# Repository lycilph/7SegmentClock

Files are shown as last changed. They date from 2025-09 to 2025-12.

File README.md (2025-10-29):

# Mechanical Clock Project

## Overview
This repository contains the code, schematics, and documentation for building a custom mechanical clock using four digit modules in a 24-hour format. Each digit is driven by a stepper motor for mechanical display, controlled via an ESP32-S3 Super Mini master module over I2C. The project includes homing functionality with Hall effect sensors and LED indicators for status.

The setup is modular, with two digit modules on each side of the master (e.g., left2 ← left1 ← master → right1 → right2). Power is supplied externally at 5V, and modules are connected using JST XH connectors.

**Key Features:**
- 24-hour time display with mechanical digits.
- Stepper motor control for each digit.
- Automatic homing using Hall sensors.
- I2C communication with voltage level shifting for safety.
- Modular design for easy assembly and expansion.

## Components
### Master Module
- ESP32-S3 Super Mini (controls I2C bus and logic).

### Per Digit Module (x4)
- PCF8575 GPIO expander (I2C to GPIO).
- ULN2003 driver board (for stepper control).
- 28BYJ-48 stepper motor (drives the digit mechanism).
- A3144 Hall effect sensor (for homing).
- Red LED (homing in progress indicator).

### Additional Hardware
- External 5V power supply (2A+ recommended).
- Bidirectional I2C level shifter (e.g., BSS138-based, 4-channel) – **critical** to bridge 3.3V (ESP32) and 5V (PCF8575).
- Resistors: 4.7kΩ (I2C pull-ups x4), 10kΩ (A3144 pull-up x4), 330Ω (LED current limiter x4).
- Capacitors: 0.1µF ceramic (decoupling for each IC), 10-100µF electrolytic (at power entry).
- Wires: 20-22 AWG for power/GND; twisted-pair for SDA/SCL.
- Connectors: JST XH 4-pin (5V, GND, SDA, SCL).

## Usage
- Power the system; ESP32 boots and initializes modules.
- Clock syncs via NTP (add WiFi code if desired) or manual set.
- Homing: On startup, each digit homes using Hall sensor; LED blinks during process.
- Display updates every minute via steppers.
---

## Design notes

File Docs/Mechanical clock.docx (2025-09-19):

# Project Architecture Overview (Google AI Studio)

This design uses a logic level shifter to create two distinct voltage zones:

- 3.3V Control Zone: The ESP32-S3 microcontroller.
- 5V Actuator Zone: All four-digit modules, including their PCF8575 GPIO expanders, stepper drivers, sensors, and LEDs.

This approach eliminates the need for individual voltage dividers on each module, resulting in a cleaner and more reliable build.

### Required Components Checklist

Control:

- ESP32-S3 Super Mini (x1)
- Bi-directional Logic Level Shifter (1x, 2-channel minimum)

Digit Modules (x4 of each):

- PCF8575 I2C GPIO Expander
- ULN2003 Stepper Driver Board
- 28BYJ-48 Stepper Motor
- A3144 Hall Effect Sensor
- Red LED

Passive Components:

- Power Supply: 5V DC, rated for 2 Amps or more.
- 330Ω Resistors (x4): For the homing LEDs.
- 4.7kΩ Resistors (x4): For I2C pull-ups (2 for the 3.3V side, 2 for the 5V side). Note: Some shifter boards have built-in resistors; check your board’s documentation.
- 0.1µF (100nF) Ceramic Capacitors (Optional but Recommended): Place one next to each IC (ESP32 and each PCF8575) for power stability.

### Wiring Instructions

#### Step 1: Power Distribution

1. Connect your 5V/2A power supply to create your main 5V Rail and GND Rail.
2. Power the ESP32-S3:
  - Connect the 5V Rail to the VIN (or 5V) pin.
  - Connect the GND Rail to the GND pin.
3. The 3V3 pin on the ESP32 is now your 3.3V Source.

#### Step 2: Logic Level Shifter & I2C Bus

This shifter bridges the 3.3V ESP32 and the 5V modules.

1. Power the Shifter:
  - HV (High Voltage) -> 5V Rail
  - LV (Low Voltage) -> ESP32 3V3 pin
  - GND -> GND Rail
2. Connect the ESP32 (Low Voltage Side):
  - ESP32 SDA pin -> Shifter LV1
  - ESP32 SCL pin -> Shifter LV2
  - Add a 4.7kΩ pull-up resistor from LV1 to 3.3V.
  - Add a 4.7kΩ pull-up resistor from LV2 to 3.3V.
3. Connect the Modules (High Voltage Side):
  - Shifter HV1 -> SDA pin of all four PCF8575 modules.
  - Shifter HV2 -> SCL pin of all four PCF8575 modules.
  - Add a 4.7kΩ pull-up resistor from HV1 to the 5V Rail.
  - Add a 4.7kΩ pull-up resistor from HV2 to the 5V Rail.

#### Step 3: Set Unique I2C Addresses

This is critical. Each PCF8575 must have a unique address. Set them by connecting the address pins (A0, A1, A2) to either GND (for 0) or 5V (for 1).

Module | A2 | A1 | A0 | I2C Address
Digit 1 | GND | GND | GND | 0x20
Digit 2 | GND | GND | 5V | 0x21
Digit 3 | GND | 5V | GND | 0x22
Digit 4 | 5V | GND | GND | 0x23

You can use other combinations, just ensure each one is unique.

#### Step 4: Wiring a Single Digit Module (Repeat 4 times)

All components in the module run on 5V.

1. Power:
  - PCF8575 VCC -> 5V Rail
  - ULN2003 + -> 5V Rail
  - A3144 VCC -> 5V Rail
  - Connect all GND pins on the module to the common GND Rail.
2. Connections:
  - Stepper Motor:
    - Connect the 28BYJ-48 plug into the ULN2003 driver board.
    - PCF8575 P0 -> ULN2003 IN1
    - PCF8575 P1 -> ULN2003 IN2
    - PCF8575 P2 -> ULN2003 IN3
    - PCF8575 P3 -> ULN2003 IN4
  - Homing Sensor (A3144):
    - A3144 Output -> PCF8575 input pin (e.g., P5). No other components are needed.
  - Homing LED:
    - ~~PCF8575 output pin (e.g.,~~ ~~P4~~~~) ->~~ ~~330Ω Resistor~~ ~~-> LED Anode (+)~~
    - ~~LED Cathode (-) ->~~ ~~GND Rail~~
    - 5V → 330Ω resistor → LED anode; cathode to PCF8575 output (e.g., P05). Active-low.

### Final Sanity Check

Before powering on, review these critical points:

1. Power Supply: Ensure your 5V power supply can provide at least 2 Amps. This is the most common cause of instability when motors are running.
2. No 5V to ESP32: Confirm that no 5V signals are connected directly to any ESP32 I/O pin. The logic level shifter is the only component bridging the two voltage levels.
3. Unique I2C Addresses: Double-check the A0/A1/A2 wiring on each of the four PCF8575 modules. If any two are the same, the I2C bus will fail.
4. Grounds are Common: All components (ESP32, shifter, and all four modules) must share a common ground connection.

# Extra (from ChatGPT)

Specific resistors & capacitors to use (concrete)

- I²C pull-ups: 10 kΩ to 3.3 V on ESP side; 4.7 kΩ to 5 V on module side. If bus is long or many devices, use 4.7 kΩ (or 2.2 kΩ for 400 kHz).
- PCF8575 INT pull-up: 10 kΩ to 3.3 V (ESP side).
- Hall sensor (A3144) output pull-up: if you connect A3144 OUT to a PCF8575 input, pull-up to 5 V (10 kΩ) on module (optional if you trust PCF8575 input behavior). If you connect A3144 OUT to ESP32 directly, use 10 kΩ to 3.3 V and confirm open-collector nature.
- LED resistor (5 V drive): 1 kΩ (≈3 mA) or 470 Ω (≈6–7 mA) depending on desired brightness.
- Decoupling: 100 nF ceramic at every IC power pin. Motor bulk: 470–1000 µF electrolytic on the 5 V rail near the motor feed.
- Small 0.1 µF across the A3144 VCC–GND on the module to stabilize sensor supply.

# Checking Level-shifter for built-in pull-ups (Gemini)

Yes, you can absolutely be sure by using a multimeter. It's the perfect tool for the job.

You can also often tell just by looking at the board.

## Using a Multimeter multimeter

Here is the step-by-step process. This must be done with the level shifter completely disconnected and unpowered.

1. Prepare Your Multimeter
  - Set your multimeter to measure resistance (Ω).
  - Choose a range like 20kΩ, as most built-in pull-up resistors are between 1kΩ and 10kΩ.
2. Test the High Voltage (HV) Side
  - Place one probe on the HV pin.
  - Place the other probe on the SDA_HV pin (sometimes labeled HV2).
  - Check the reading.
  - Now, keep the first probe on the HV pin and move the second probe to the SCL_HV pin (sometimes labeled HV1).
  - Check the reading.
3. Test the Low Voltage (LV) Side
  - Place one probe on the LV pin.
  - Place the other probe on the SDA_LV pin (sometimes labeled LV2).
  - Check the reading.
  - Now, keep the first probe on the LV pin and move the second probe to the SCL_LV pin (sometimes labeled LV1).
  - Check the reading.

## Interpreting the Results 💡

- If you see a stable value between 1kΩ and 10kΩ: Congratulations, a pull-up resistor is present on that pin. A reading of "10.0" on the 20kΩ scale means you have a 10kΩ resistor.
- If your meter reads "OL" (Over Limit), "infinite," or just doesn't change from its default state: There is no pull-up resistor connecting those two pins. You will need to add your own.

You should get a consistent reading for both the SDA and SCL pins on a given side (e.g., both pins on the HV side will have 10kΩ pull-ups).

## A Quick Visual Check 👀

You can often spot the resistors just by looking.

Look for small, black surface-mount (SMD) components near the pins. They are usually marked with a numerical code. For a 10kΩ resistor, you will typically see the number "103" (which means 10 followed by 3 zeros, or 10,000). You can follow the copper traces on the board to see if they connect the SDA/SCL pins to the HV/LV pins through these components.

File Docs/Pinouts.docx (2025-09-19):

# Pinouts

## ESP32-S3 Super mini

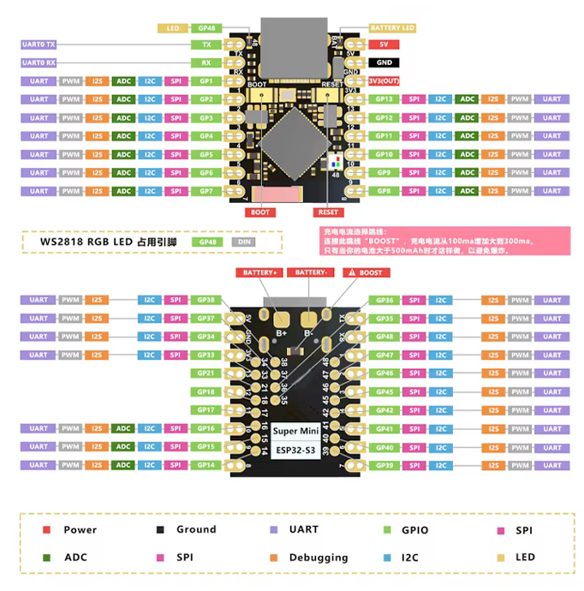
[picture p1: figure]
ESP32-S3 Super Mini pinout
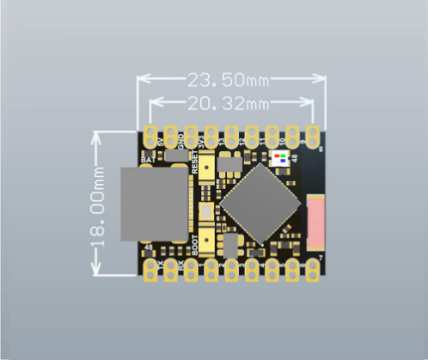
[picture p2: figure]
ESP32-S3 Super Mini dimensions - height, width

## PCF8575

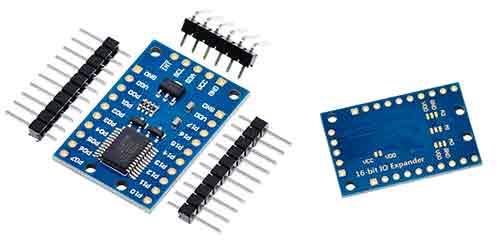
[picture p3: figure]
arduino-pcf8575-componente
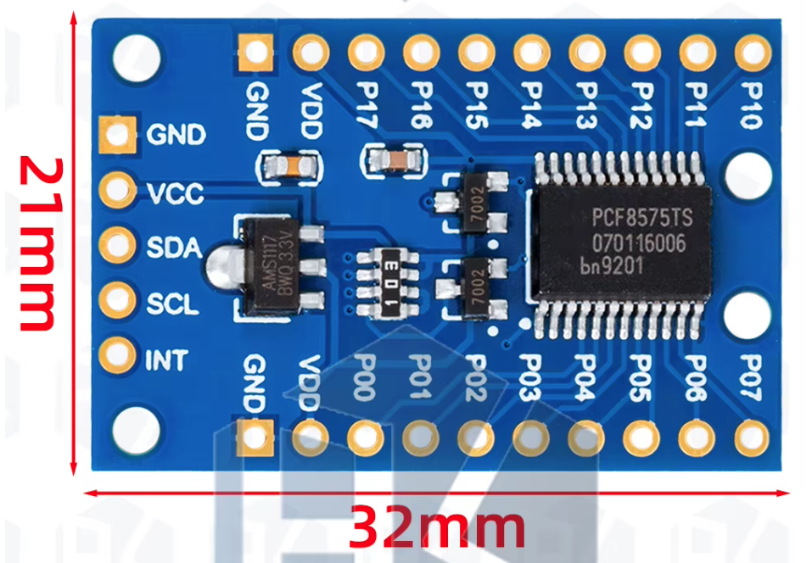
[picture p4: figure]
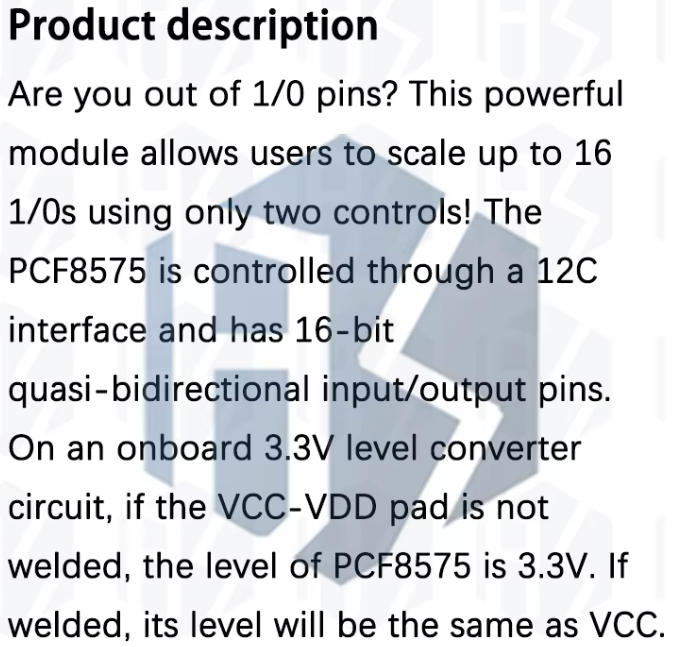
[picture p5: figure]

## A3144

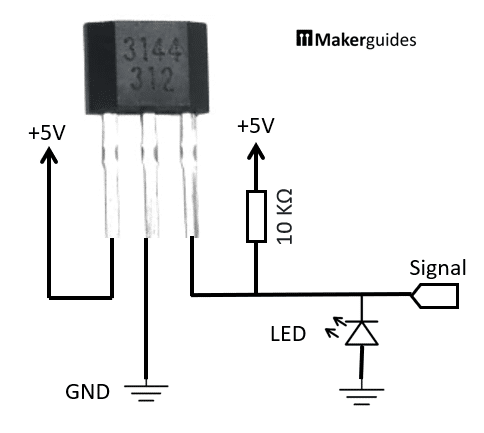
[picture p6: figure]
Testing the A3144 Hall Effect Sensor

## ULN2003

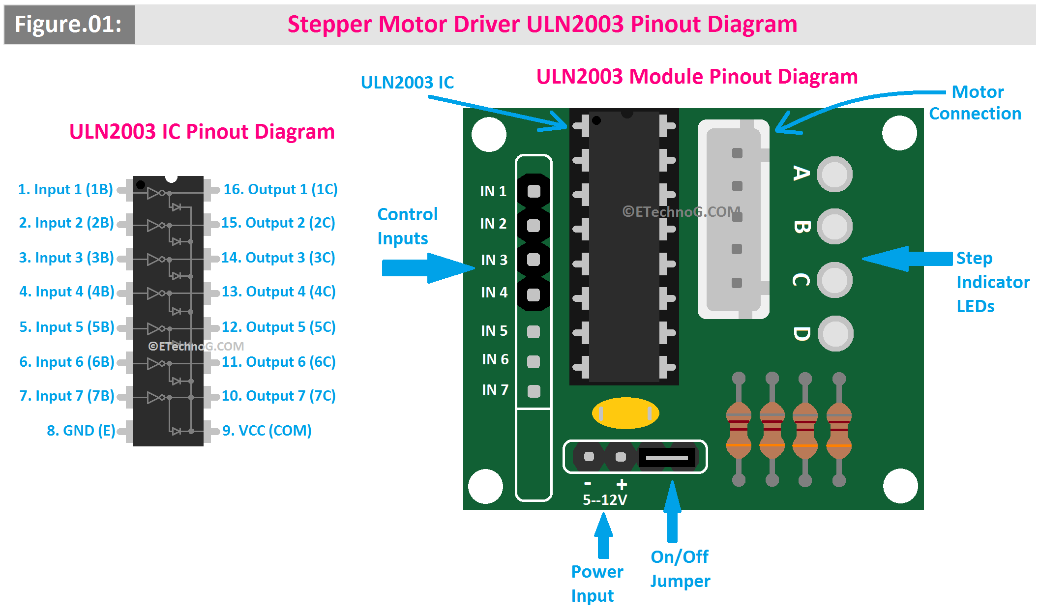
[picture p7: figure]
ULN2003 IC Pinout Diagram, ULN2003 Module Pinout Diagram

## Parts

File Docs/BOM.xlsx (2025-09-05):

Item | # | Price | Total | Link
28BYJ-48 Stepper motor | 5 | 11.88 | 57.96 | https://www.aliexpress.com/item/1005005929104242.html?curPageLogUid=ijdTWuI513CS
PCF8575 | 5 | 15.62 | 54.79 | https://www.aliexpress.com/item/1005009410052950.html?curPageLogUid=l2r6LPoUxHaU
A3144 | 10 | 13.23 | 13.23 | https://www.aliexpress.com/item/1005006136921399.html?curPageLogUid=vVF7NFhDA8yi
N52 5x3 magnets | 50 | 31.35 | 31.35 | https://www.aliexpress.com/item/1005009339285539.html?curPageLogUid=vOYvfErc0nGl
USB-c connector | 5 | 17.12 | 17.12 | https://www.aliexpress.com/item/1005007469640237.html?productId=1005007469640237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
Bearings 608zz | 10 | 22.04 | 22.04 | https://www.aliexpress.com/item/1005008612618353.html?curPageLogUid=ml2DoczdEAmw
RTC DS1307 | 2 | 9.81 | 19.62 | https://www.aliexpress.com/item/1005007143542894.html?curPageLogUid=M9aB6QRXBudq
Wires | 1 | 79.27 | 79.27 | https://www.aliexpress.com/item/1005009726416788.html?curPageLogUid=W2luivYyj2qX
JST connector set | 1 | 126.8 | 126.8 | https://www.aliexpress.com/item/4001142557350.html?curPageLogUid=jYMhtkVZFTlC
M3 Bolts
 |  |  | 422.18

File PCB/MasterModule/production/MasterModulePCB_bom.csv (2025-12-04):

Designator | Footprint | Quantity | Value | LCSC Part #
C1 | C_Radial_D8.0mm_H11.5mm_P3.50mm | 1 | 1000uf
C2, C3 | C_Disc_D3.0mm_W2.0mm_P2.50mm | 2 | 100nf
CON1 | JST_Connector_Footprint | 1 | Male Connector
CON2 | JST_Connector_Footprint | 1 | Femail Connector
L1 | PinHeader_1x02_P2.54mm_Vertical | 1 | Yellow LED
L2 | PinHeader_1x02_P2.54mm_Vertical | 1 | Green LED
L3 | PinHeader_1x02_P2.54mm_Vertical | 1 | Power LED
P1 | Power_Connection_Footprint | 1 | USB Power
R1, R2 | R_Axial_DIN0204_L3.6mm_D1.6mm_P7.62mm_Horizontal | 2 | 220
R3 | R_Axial_DIN0204_L3.6mm_D1.6mm_P7.62mm_Horizontal | 1 | 330
R4, R5, R6, R7 | R_Axial_DIN0204_L3.6mm_D1.6mm_P7.62mm_Horizontal | 4 | 4k7
RTC1 | RTC_Module_Footprint | 1 | Real Time Clock
U1 | I2C_Level_Shifter | 1 | I2C Level Shifter
U2 | PinHeader_1x05_P2.54mm_Vertical | 1 | ESP32
U3 | PinHeader_1x05_P2.54mm_Vertical | 1 | ESP32 Signals
U4 | PinHeader_1x06_P2.54mm_Vertical | 1 | Controls

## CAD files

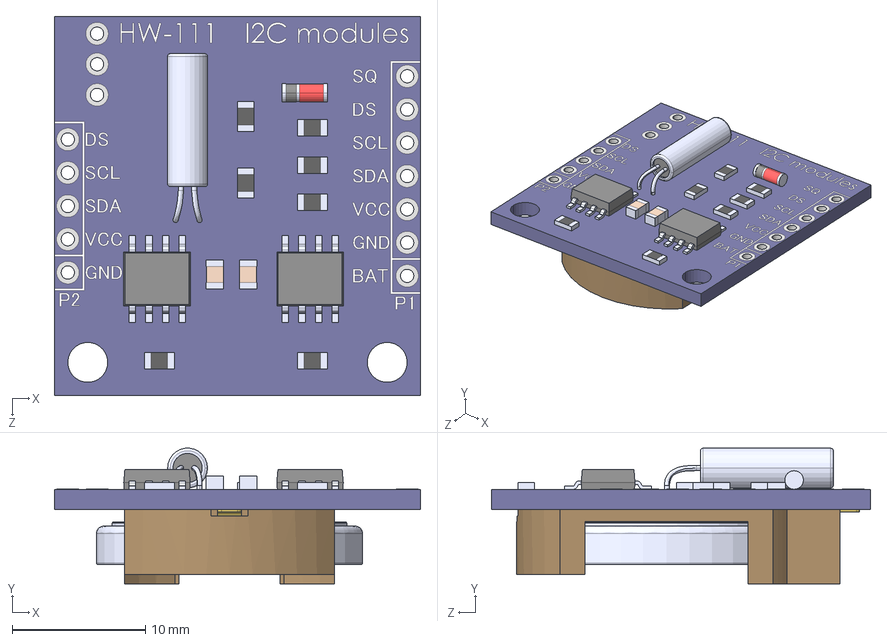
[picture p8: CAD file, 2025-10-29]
CAD/RTCmodule_DS1307.STEP
27.5 x 10.2 x 28.5 mm
HW-111_MainBoad
IC_DS1307Z_1901GM_153AA x 2
セラミックコンデンサs x 2
チップコンデンサ x 7
Oscillator
Battery Holder_LIR2032
TerminalPlus
TerminalMinus
LIR2032_Battery
D1daiord

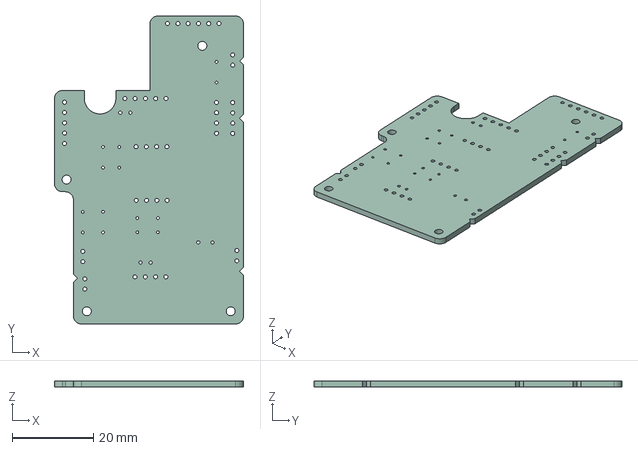
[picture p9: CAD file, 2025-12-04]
PCB/MasterModule.step
46.7 x 76.0 x 1.51 mm

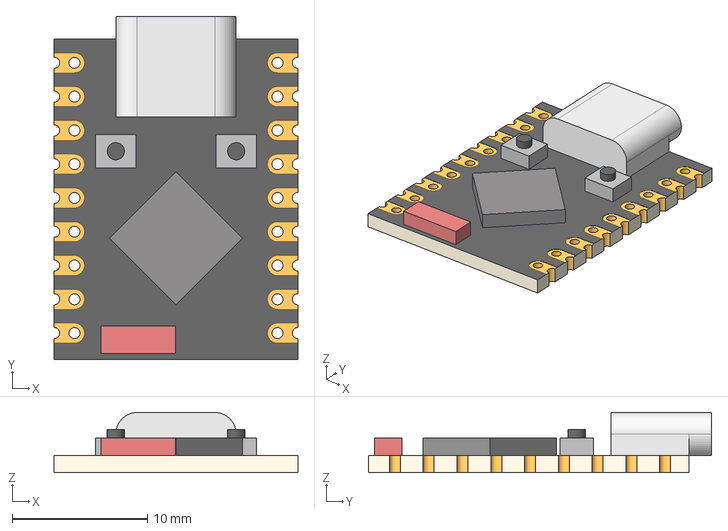
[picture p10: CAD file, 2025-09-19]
CAD/ESP32S3 Super Mini.step
18.0 x 25.4 x 4.45 mm

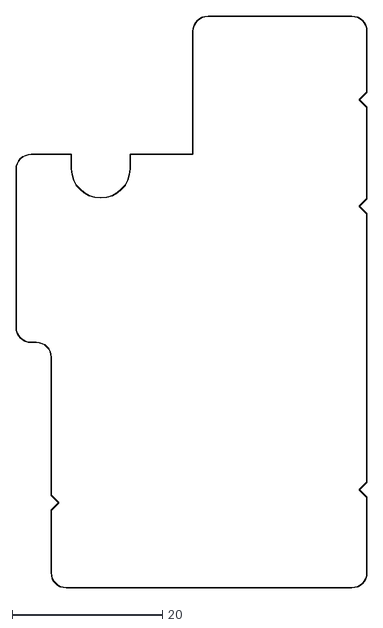
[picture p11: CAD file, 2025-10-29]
PCB/PCB Outline.dxf
46.7 x 76.0

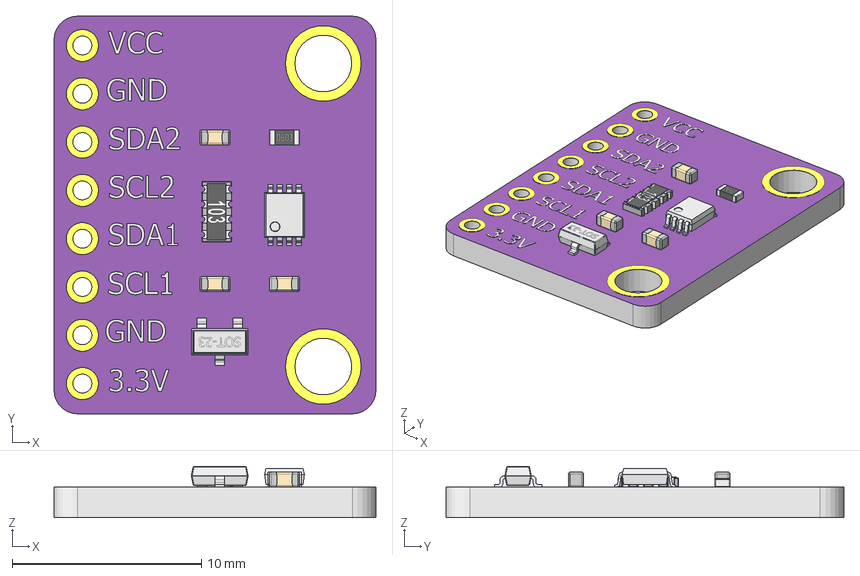
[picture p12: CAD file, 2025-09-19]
CAD/pca9306.step
17.0 x 21.0 x 2.70 mm
Board
ť1
ť2 x 2
SOT23-3
C0603_001
C0603_002
C0603_003
VSSSOP8
CAT16-J4

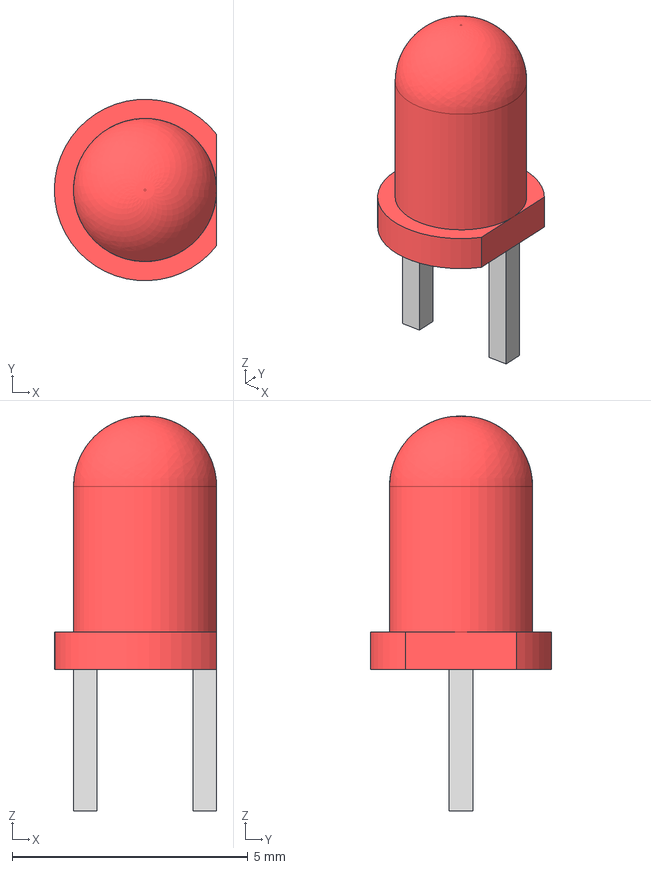
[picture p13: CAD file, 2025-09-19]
CAD/LED 3mm Red 3mm Leads.step
3.45 x 3.85 x 8.38 mm
LEDBody
Lead1Body
Lead2Body

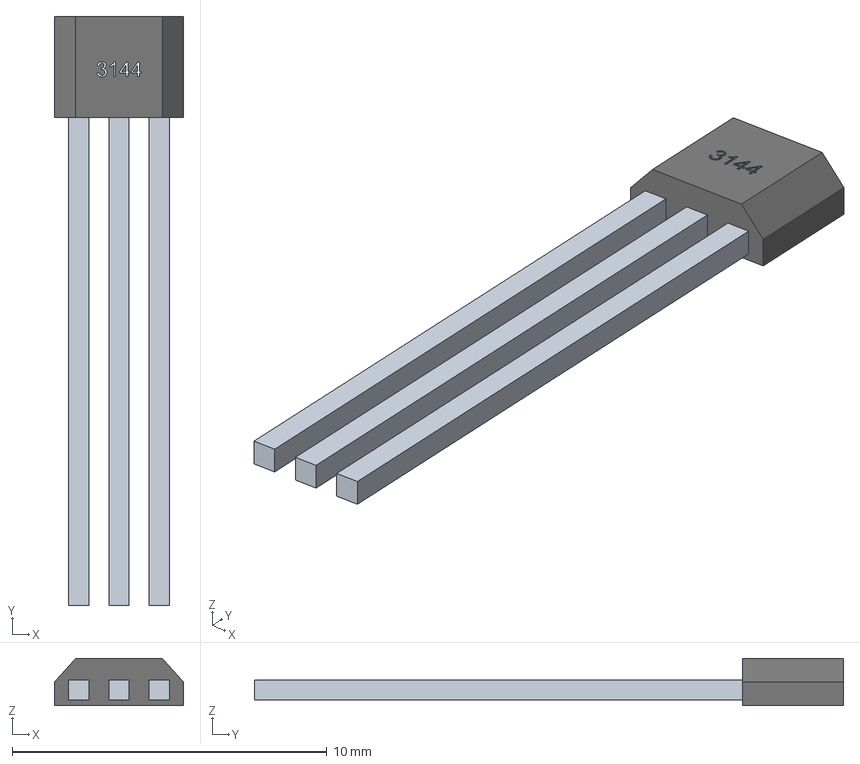
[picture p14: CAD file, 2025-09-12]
CAD/Hall Effect Sensor Sunkee A3144 v4.step
4.10 x 18.7 x 1.50 mm

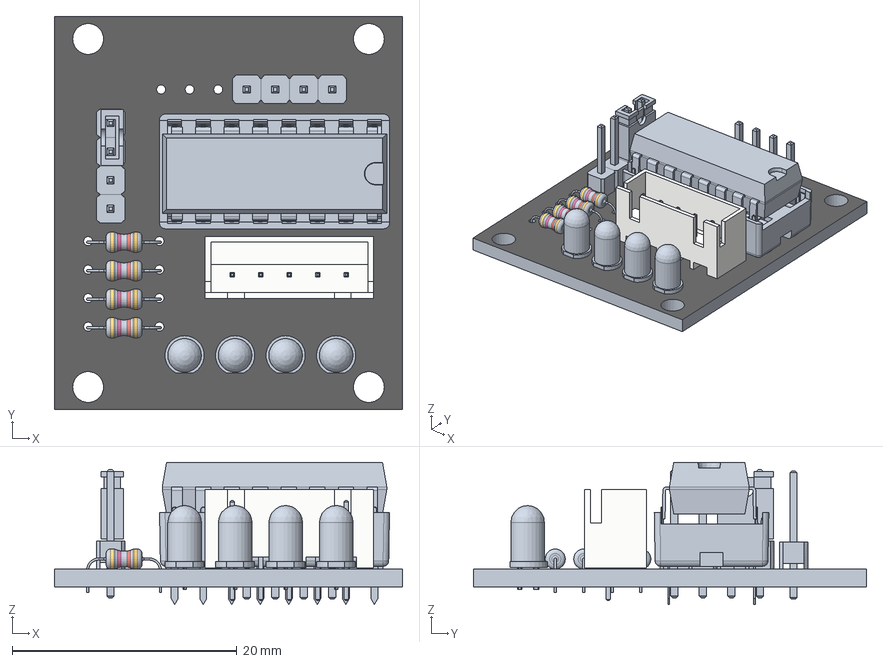
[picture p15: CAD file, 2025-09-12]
CAD/ULN2003 Stepper Driver.stp
31.0 x 35.0 x 12.7 mm
pcb
jumper_connector
r205 x 4
conn_lead x 5
spacer x 4
pin x 4
spacer (1) x 4
pin (1) x 4
LED 3mm x 4
package
lead
housing
pins

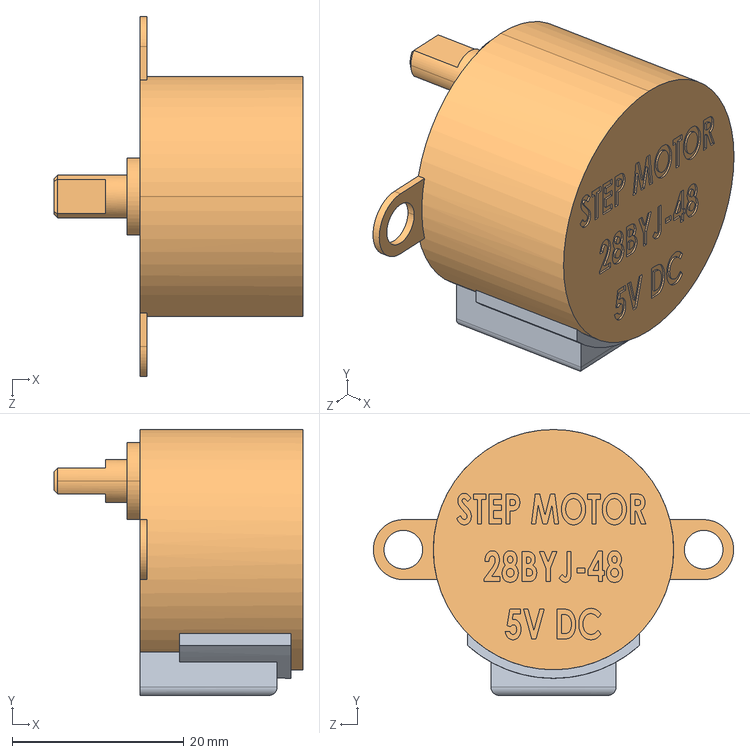
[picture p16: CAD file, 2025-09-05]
CAD/Stepper motor 28BYJ-48 5V.STEP
29.0 x 31.0 x 42.0 mm

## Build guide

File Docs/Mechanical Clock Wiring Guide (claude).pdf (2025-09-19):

## Mechanical Clock Wiring Guide

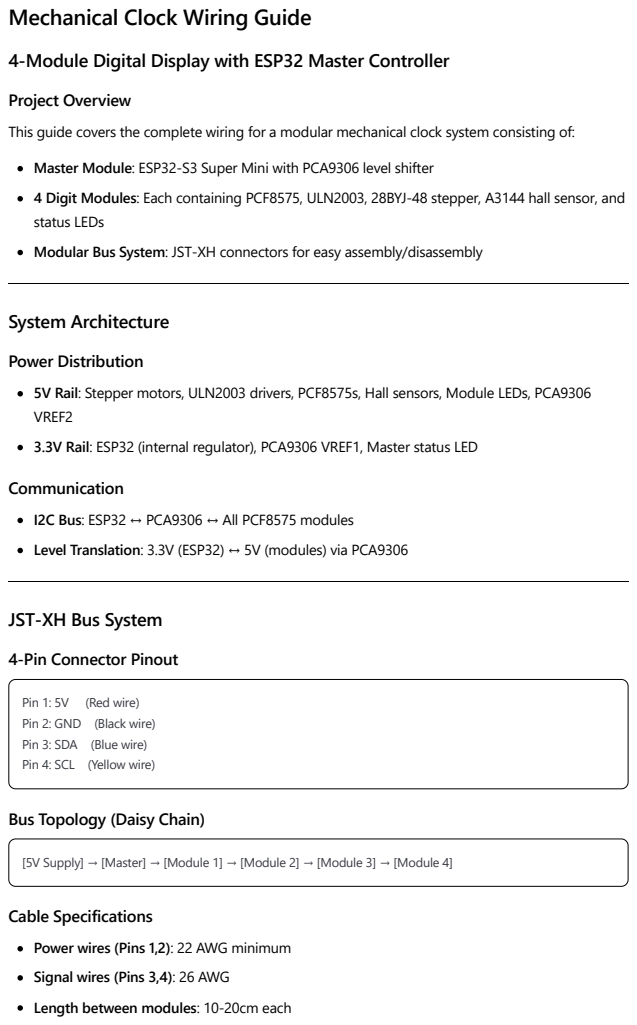
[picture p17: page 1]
System Architecture

4-Module Digital Display with ESP32 Master Controller

Project Overview
This guide covers the complete wiring for a modular mechanical clock system consisting of:
Master Module: ESP32-S3 Super Mini with PCA9306 level shifter
4 Digit Modules: Each containing PCF8575, ULN2003, 28BYJ-48 stepper, A3144 hall sensor, and
status LEDs
Modular Bus System: JST-XH connectors for easy assembly/disassembly

Power Distribution
5V Rail: Stepper motors, ULN2003 drivers, PCF8575s, Hall sensors, Module LEDs, PCA9306
VREF2
3.3V Rail: ESP32 (internal regulator), PCA9306 VREF1, Master status LED
Communication
I2C Bus: ESP32 ↔ PCA9306 ↔ All PCF8575 modules
Level Translation: 3.3V (ESP32) ↔ 5V (modules) via PCA9306

JST-XH Bus System

4-Pin Connector Pinout

Pin 1: 5V (Red wire)
Pin 2: GND (Black wire)
Pin 3: SDA (Blue wire)
Pin 4: SCL (Yellow wire)

Bus Topology (Daisy Chain)

[5V Supply] → [Master] → [Module 1] → [Module 2] → [Module 3] → [Module 4]

Cable Specifications
Power wires (Pins 1,2): 22 AWG minimum
Signal wires (Pins 3,4): 26 AWG
Length between modules: 10-20cm each

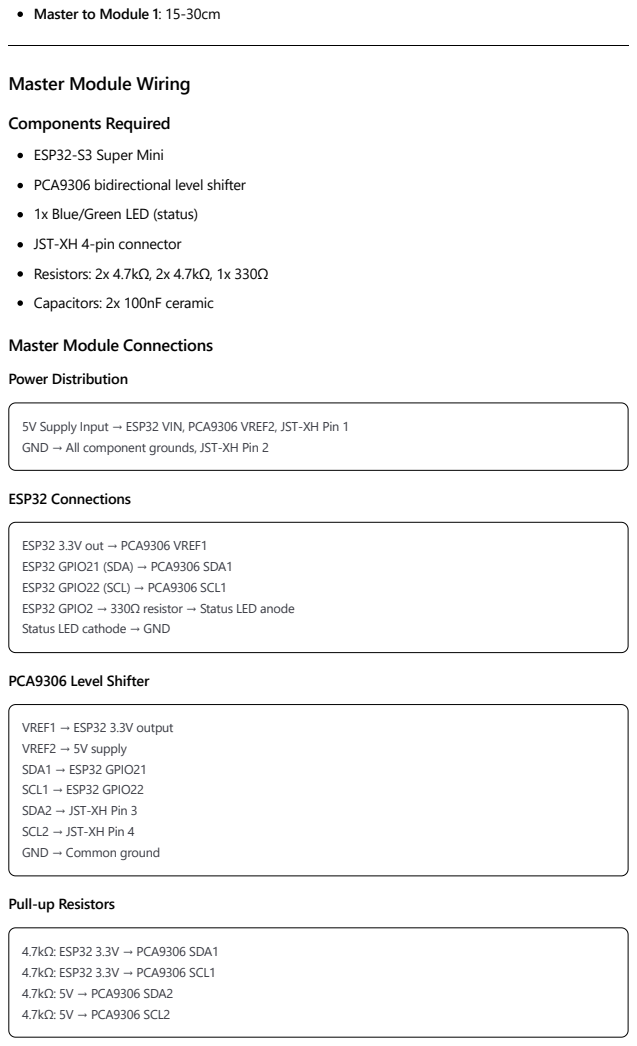
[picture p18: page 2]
ESP32 Connections; PCA9306 Level Shifter; 4.7kΩ: ESP32 3.3V → PCA9306 SDA1 4.7kΩ: ESP32 3.3V → PCA9306 SCL1 4.7kΩ: 5V → PCA9306 SDA2 4.7kΩ: 5V → PCA9306 SCL2

Master to Module 1: 15-30cm

Master Module Wiring

Components Required
ESP32-S3 Super Mini
PCA9306 bidirectional level shifter
1x Blue/Green LED (status)
JST-XH 4-pin connector
Resistors: 2x 4.7kΩ, 2x 4.7kΩ, 1x 330Ω
Capacitors: 2x 100nF ceramic
Master Module Connections
Power Distribution

5V Supply Input → ESP32 VIN, PCA9306 VREF2, JST-XH Pin 1
GND → All component grounds, JST-XH Pin 2

ESP32 3.3V out → PCA9306 VREF1
ESP32 GPIO21 (SDA) → PCA9306 SDA1
ESP32 GPIO22 (SCL) → PCA9306 SCL1
ESP32 GPIO2 → 330Ω resistor → Status LED anode
Status LED cathode → GND

VREF1 → ESP32 3.3V output
VREF2 → 5V supply
SDA1 → ESP32 GPIO21
SCL1 → ESP32 GPIO22
SDA2 → JST-XH Pin 3
SCL2 → JST-XH Pin 4
GND → Common ground

Pull-up Resistors

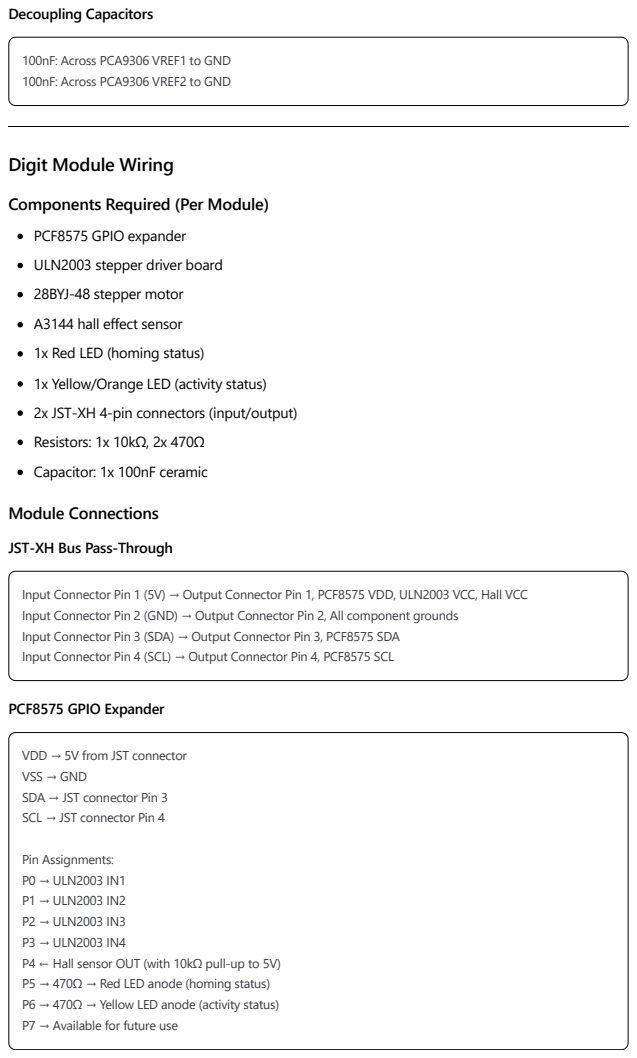
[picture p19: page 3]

Components Required (Per Module)
PCF8575 GPIO expander
ULN2003 stepper driver board
28BYJ-48 stepper motor
A3144 hall effect sensor
1x Red LED (homing status)
1x Yellow/Orange LED (activity status)
2x JST-XH 4-pin connectors (input/output)
Resistors: 1x 10kΩ, 2x 470Ω
Capacitor: 1x 100nF ceramic
Module Connections
JST-XH Bus Pass-Through

Input Connector Pin 1 (5V) → Output Connector Pin 1, PCF8575 VDD, ULN2003 VCC, Hall VCC
Input Connector Pin 2 (GND) → Output Connector Pin 2, All component grounds
Input Connector Pin 3 (SDA) → Output Connector Pin 3, PCF8575 SDA
Input Connector Pin 4 (SCL) → Output Connector Pin 4, PCF8575 SCL

VDD → 5V from JST connector
VSS → GND
SDA → JST connector Pin 3
SCL → JST connector Pin 4

Pin Assignments:
P0 → ULN2003 IN1
P1 → ULN2003 IN2
P2 → ULN2003 IN3
P3 → ULN2003 IN4
P4 ← Hall sensor OUT (with 10kΩ pull-up to 5V)
P5 → 470Ω → Red LED anode (homing status)
P6 → 470Ω → Yellow LED anode (activity status)
P7 → Available for future use

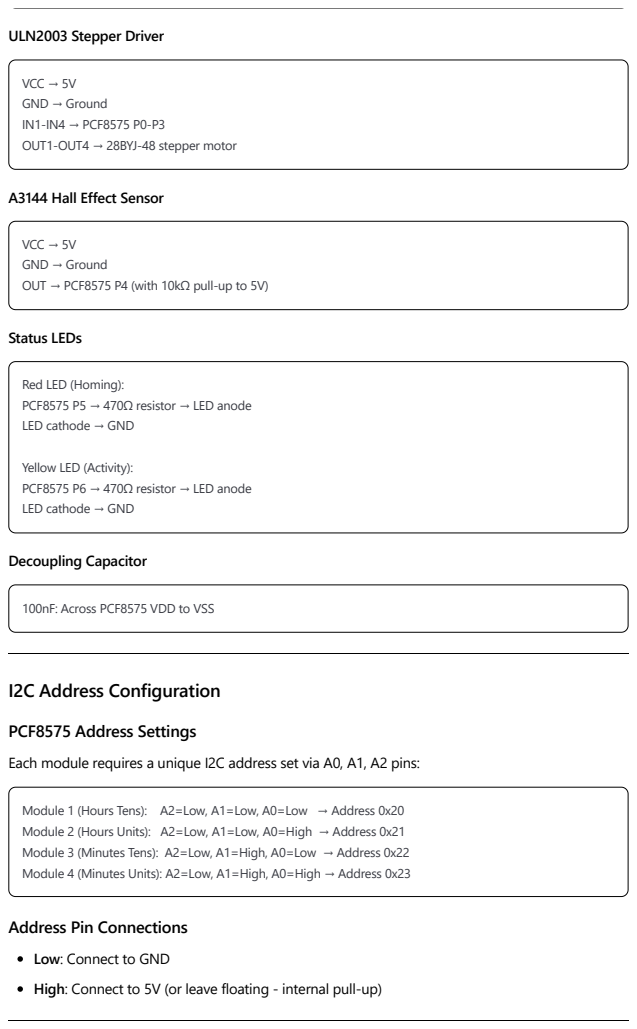
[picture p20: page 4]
ULN2003 Stepper Driver; Status LEDs; Decoupling Capacitor; I2C Address Configuration; VCC → 5V GND → Ground IN1-IN4 → PCF8575 P0-P3 OUT1-OUT4 → 28BYJ-48 stepper motor

A3144 Hall Effect Sensor

VCC → 5V
GND → Ground
OUT → PCF8575 P4 (with 10kΩ pull-up to 5V)

Red LED (Homing):
PCF8575 P5 → 470Ω resistor → LED anode
LED cathode → GND

Yellow LED (Activity):
PCF8575 P6 → 470Ω resistor → LED anode

100nF: Across PCF8575 VDD to VSS

PCF8575 Address Settings
Each module requires a unique I2C address set via A0, A1, A2 pins:

Module 1 (Hours Tens): A2=Low, A1=Low, A0=Low → Address 0x20
Module 2 (Hours Units): A2=Low, A1=Low, A0=High → Address 0x21
Module 3 (Minutes Tens): A2=Low, A1=High, A0=Low → Address 0x22
Module 4 (Minutes Units): A2=Low, A1=High, A0=High → Address 0x23

Address Pin Connections
Low: Connect to GND
High: Connect to 5V (or leave floating - internal pull-up)

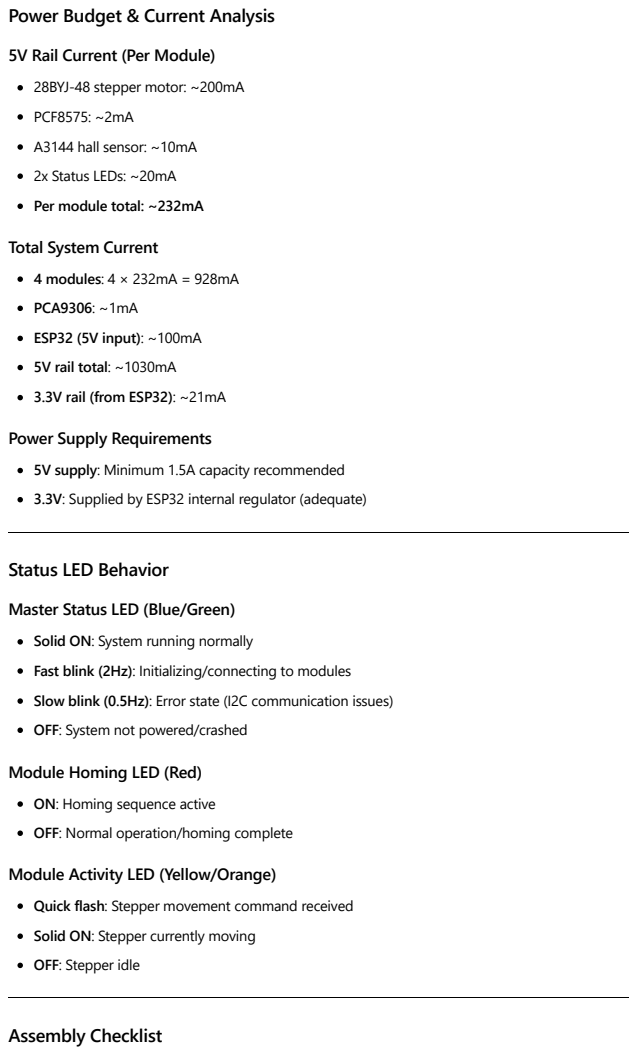
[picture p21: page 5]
Assembly Checklist

Power Budget & Current Analysis

5V Rail Current (Per Module)
28BYJ-48 stepper motor: ~200mA
PCF8575: ~2mA
A3144 hall sensor: ~10mA
2x Status LEDs: ~20mA
Per module total: ~232mA
Total System Current
4 modules: 4 × 232mA = 928mA
PCA9306: ~1mA
ESP32 (5V input): ~100mA
5V rail total: ~1030mA
3.3V rail (from ESP32): ~21mA
Power Supply Requirements
5V supply: Minimum 1.5A capacity recommended
3.3V: Supplied by ESP32 internal regulator (adequate)

Status LED Behavior

Master Status LED (Blue/Green)
Solid ON: System running normally
Fast blink (2Hz): Initializing/connecting to modules
Slow blink (0.5Hz): Error state (I2C communication issues)
OFF: System not powered/crashed
Module Homing LED (Red)
ON: Homing sequence active
OFF: Normal operation/homing complete
Module Activity LED (Yellow/Orange)
Quick flash: Stepper movement command received
Solid ON: Stepper currently moving
OFF: Stepper idle

Before Starting
All JST-XH connectors and cables prepared
Color-coded wires: Red(5V), Black(GND), Blue(SDA), Yellow(SCL) All components and resistor values verified
Multimeter ready for continuity testing

Master Module Assembly
ESP32-S3 Super Mini wired
PCA9306 level shifter installed
Pull-up resistors (4x 4.7kΩ) installed
Status LED and current limiting resistor (330Ω) installed Decoupling capacitors (2x 100nF) installed
JST-XH output connector wired
Power connections tested (5V, GND)
I2C signal continuity verified

Per Module Assembly
PCF8575 I2C address set correctly (A0, A1, A2) JST-XH input and output connectors wired
PCF8575 to ULN2003 connections (P0-P3 to IN1-IN4) Hall sensor wired with pull-up resistor (10kΩ)
Status LEDs with current limiting resistors (2x 470Ω) Decoupling capacitor (100nF) installed
Stepper motor connected to ULN2003 outputs

System Integration
Modules connected in daisy chain order Power supply connected to master module All connections tight and secure
No short circuits (continuity test)
I2C bus pull-ups present on master module only

### Troubleshooting Guide

No Communication with Modules
1. Check 5V and GND on JST-XH bus
2. Verify PCA9306 power (3.3V and 5V sides)
3. Confirm I2C pull-up resistors on master module
4. Test individual modules by connecting directly to master

Module Not Responding

1. Verify unique I2C address settings
2. Check PCF8575 power and ground
3. Disconnect other modules to isolate issue
4. Verify JST-XH connector pinout and wiring

Stepper Motor Issues
1. Check ULN2003 power (5V)
2. Verify PCF8575 P0-P3 to ULN2003 IN1-IN4 connections
3. Confirm motor wiring to ULN2003 OUT1-OUT4
4. Test motor independently with known good driver

Hall Sensor Problems
1. Verify 5V power to sensor
2. Check 10kΩ pull-up resistor to 5V
3. Confirm sensor output to PCF8575 P4
4. Test sensor with magnet and multimeter

Status LED Issues
1. Check current limiting resistor values
2. Verify LED polarity (anode to resistor, cathode to GND)
3. Test PCF8575 output pins with multimeter
4. Replace suspected faulty LEDs

### Component Specifications Summary

ICs and Modules
ESP32-S3 Super Mini: 3.3V logic, built-in 5V→3.3V regulator PCA9306: Bidirectional I2C level shifter (3.3V ↔ 5V) PCF8575: 16-bit I2C GPIO expander, 5V operation ULN2003: Darlington driver array, 5V/500mA per channel 28BYJ-48: 5V stepper motor, ~200mA operation
A3144: Hall effect sensor, 3.3V-5V operation

Passive Components
Pull-up resistors: 4.7kΩ (I2C bus, hall sensor) LED resistors: 330Ω (3.3V), 470Ω (5V)

Decoupling capacitors: 100nF ceramic JST-XH connectors: 4-pin, 3A rating

### Final Notes

Design Benefits
Modular: Each digit module is self-contained and removable Scalable: Easy to add more modules or modify configuration Serviceable: Individual modules can be disconnected for repair Clean: Standardized JST-XH bus eliminates wire mess
Robust: Proper level shifting and power distribution

Safety Considerations
Use appropriate wire gauges for current capacity Ensure all connections are secure before applying power Test continuity before first power-on
Monitor current consumption during initial testing
Use strain relief on all cable connections

Software Considerations
Each PCF8575 module requires unique I2C address Implement proper I2C error handling and timeouts
Use status LEDs to provide visual feedback during operation Consider implementing module auto-discovery for robustness

Document Version: 1.0
Created for: 4-Module Mechanical Clock Project
Last Updated: September 2025

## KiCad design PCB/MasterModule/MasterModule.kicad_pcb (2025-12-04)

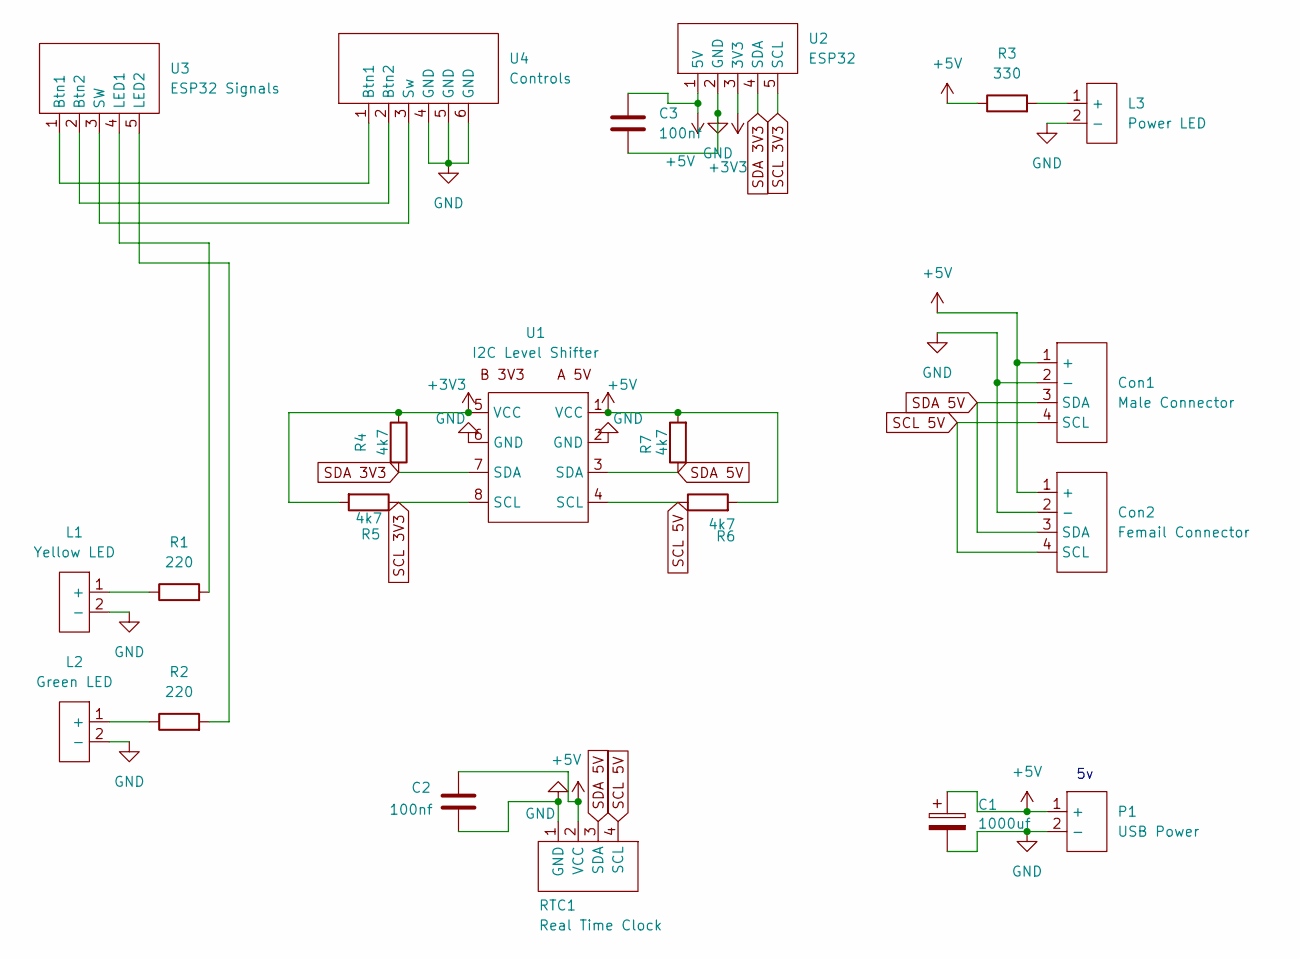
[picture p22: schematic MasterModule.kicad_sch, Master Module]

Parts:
C1: 1000uf; C_Radial_D8.0mm_H11.5mm_P3.50mm
C2, C3: 100nf; C_Disc_D3.0mm_W2.0mm_P2.50mm
Con1: Male Connector; JST_Connector_Footprint
Con2: Femail Connector; JST_Connector_Footprint
L1: Yellow LED; PinHeader_1x02_P2.54mm_Vertical
L2: Green LED; PinHeader_1x02_P2.54mm_Vertical
L3: Power LED; PinHeader_1x02_P2.54mm_Vertical
P1: USB Power; Power_Connection_Footprint
R1, R2: 220; R_Axial_DIN0204_L3.6mm_D1.6mm_P7.62mm_Horizontal
R3: 330; R_Axial_DIN0204_L3.6mm_D1.6mm_P7.62mm_Horizontal
R4, R5, R6, R7: 4k7; R_Axial_DIN0204_L3.6mm_D1.6mm_P7.62mm_Horizontal
RTC1: Real Time Clock; RTC_Module_Footprint
U1: I2C Level Shifter; I2C_Level_Shifter
U2: ESP32; PinHeader_1x05_P2.54mm_Vertical
U3: ESP32 Signals; PinHeader_1x05_P2.54mm_Vertical
U4: Controls; PinHeader_1x06_P2.54mm_Vertical

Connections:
+3V3: R4.1, R5.2, U1.5 (VCC), U2.3 (3V3)
+5V: C1.1, C2.1, C3.1, Con1.1 (+), Con2.1 (+), P1.1 (+), R3.1, R6.2, R7.2, RTC1.2 (VCC), U1.1 (VCC), U2.1 (5V)
GND: C1.2, C2.2, C3.2, Con1.2 (-), Con2.2 (-), L1.2 (-), L2.2 (-), L3.2 (-), P1.2 (-), RTC1.1 (GND), U1.2 (GND), U1.6 (GND), U2.2 (GND), U4.4 (GND), U4.5 (GND), U4.6 (GND)
unnamed: L1.1 (+), R1.1
unnamed: L2.1 (+), R2.1
unnamed: L3.1 (+), R3.2
unnamed: U3.1 (Btn1), U4.1 (Btn1)
unnamed: U3.2 (Btn2), U4.2 (Btn2)
unnamed: R1.2, U3.4 (LED1)
unnamed: R2.2, U3.5 (LED2)
unnamed: U3.3 (SW), U4.3 (Sw)
SCL 3V3: R5.1, U1.8 (SCL), U2.5 (SCL)
SCL 5V: Con1.4 (SCL), Con2.4 (SCL), R6.1, RTC1.4 (SCL), U1.4 (SCL)
SDA 3V3: R4.2, U1.7 (SDA), U2.4 (SDA)
SDA 5V: Con1.3 (SDA), Con2.3 (SDA), R7.1, RTC1.3 (SDA), U1.3 (SDA)

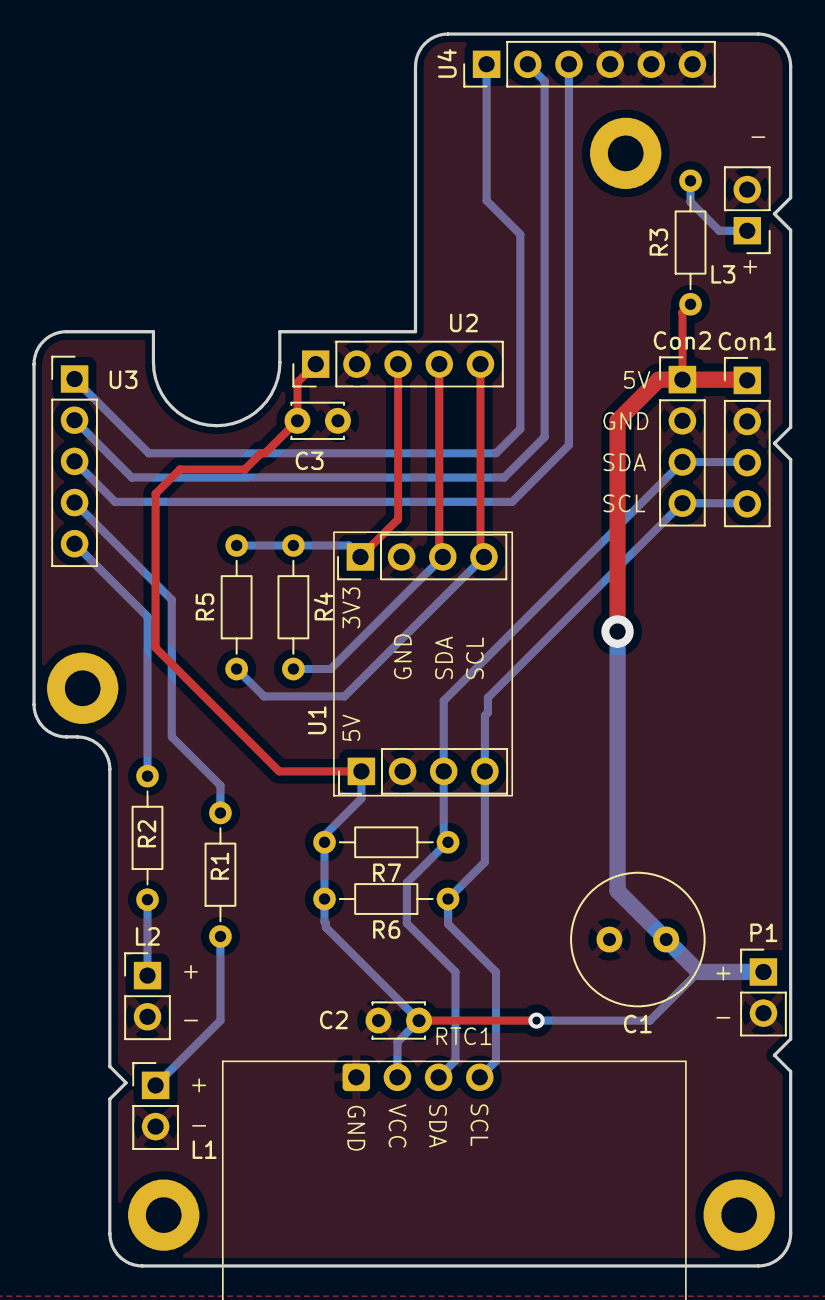
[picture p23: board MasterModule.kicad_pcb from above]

Board: 2 copper layers, 46.7 x 76.0 mm, 21 parts (0 on the bottom side), 15 nets.

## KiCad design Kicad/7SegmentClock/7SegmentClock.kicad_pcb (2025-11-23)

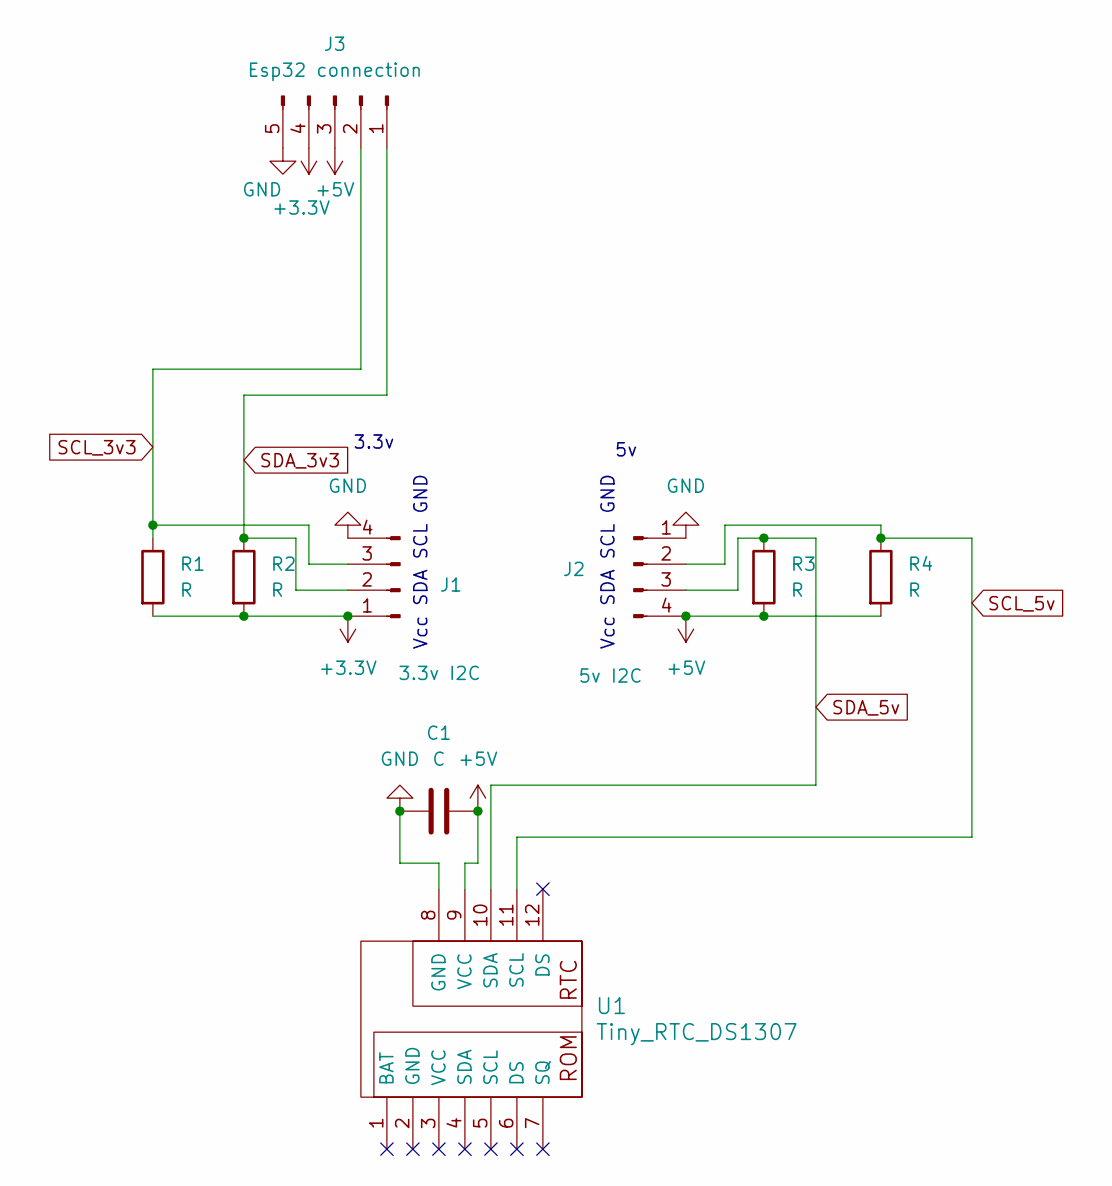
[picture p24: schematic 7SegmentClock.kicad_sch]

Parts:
C1: C; C_Disc_D3.0mm_W1.6mm_P2.50mm
J1: 3.3v I2C; PinHeader_1x04_P2.54mm_Vertical
J2: 5v I2C; PinHeader_1x04_P2.54mm_Vertical
J3: Esp32 connection; PinHeader_1x05_P2.54mm_Vertical
R1, R2, R3, R4: R; R_Axial_DIN0204_L3.6mm_D1.6mm_P5.08mm_Horizontal
U1: Tiny_RTC_DS1307

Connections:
+3.3V: J1.1, J3.4, R1.2, R2.2
+5V: C1.2, J2.4, J3.3, R3.2, R4.2, U1.9 (VCC)
GND: C1.1, J1.4, J2.1, J3.5, U1.8 (GND)
unnamed: J1.2, J3.1, R2.1
unnamed: J1.3, J3.2, R1.1
unnamed: J2.2, R4.1, U1.11 (SCL)
unnamed: J2.3, R3.1, U1.10 (SDA)

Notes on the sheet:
3.3v
Vcc SDA SCL GND

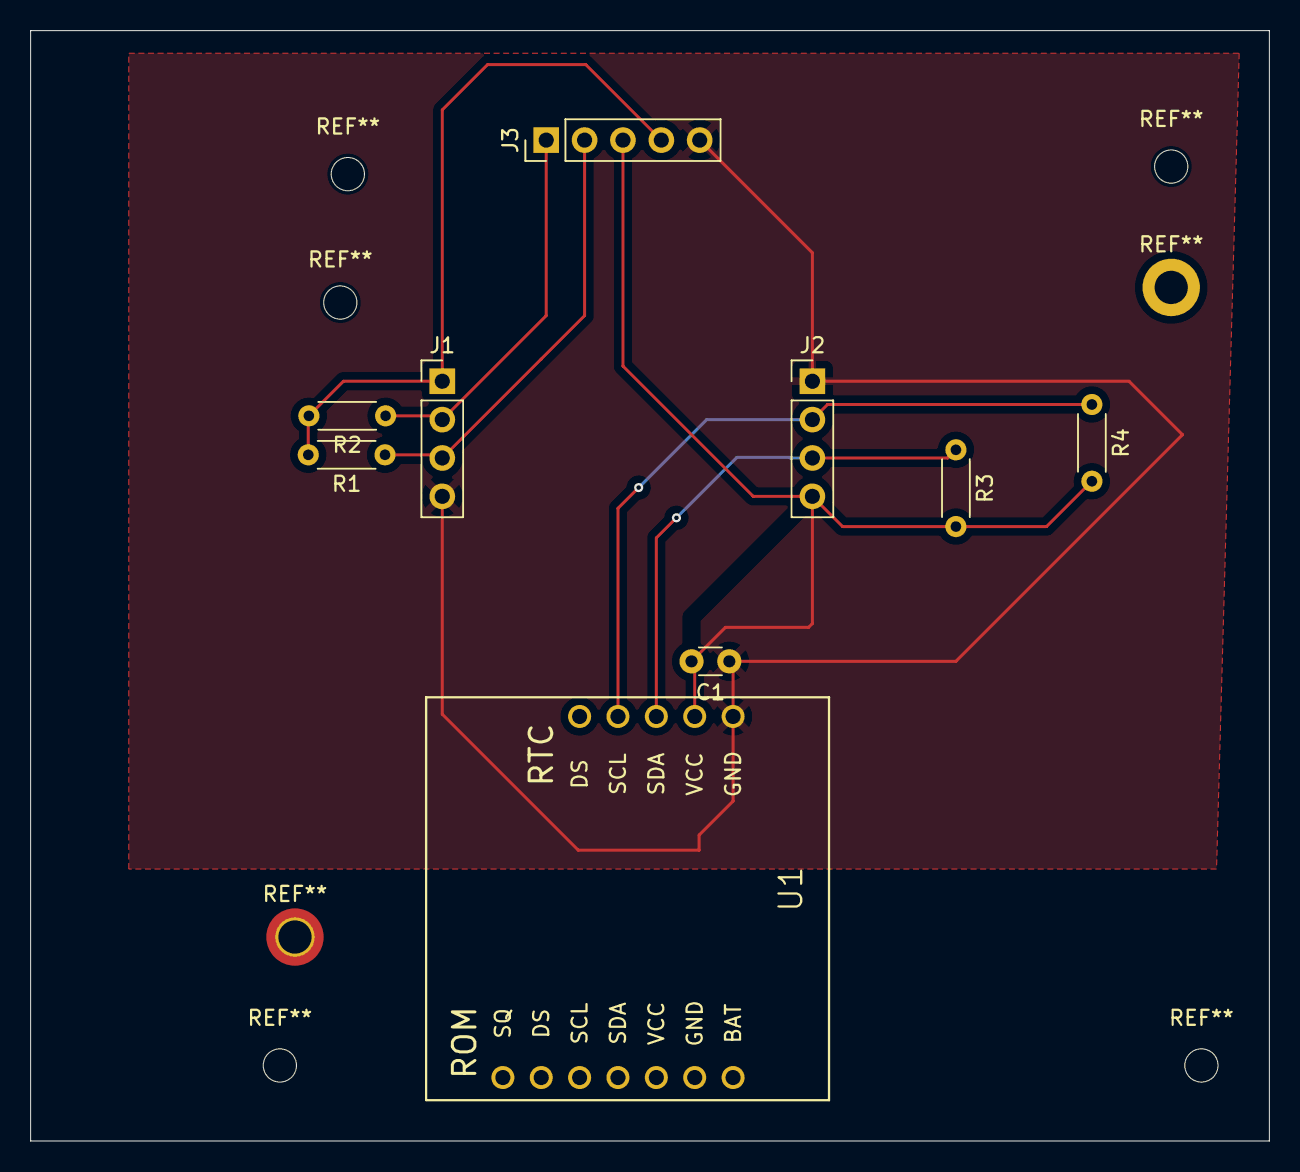
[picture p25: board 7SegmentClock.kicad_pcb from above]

Board: 2 copper layers, 82.0 x 73.5 mm, 9 parts (0 on the bottom side), 7 nets.

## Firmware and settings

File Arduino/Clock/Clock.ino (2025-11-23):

#include <Wire.h>
#include <Bounce2.h>
#include "PCF8575.h"
#include "PCFStepper.h"
#include "RTClib.h"

//#define SERIAL_DEBUG 1

uint8_t pcf_address = 0x20;

// ESP32 pins
uint8_t button1_pin = 1;
uint8_t button2_pin = 2;
uint8_t switch_pin = 3;
uint8_t led_yellow_pin = 6;
uint8_t led_green_pin = 7;

// Digit pins
uint8_t digit_led_red_pin = 11;
uint8_t digit_hall_sensor_pin = 8;

const int stepsPerRevolution = 2048;
const int stepsPerNumber = 410;

PCF8575 PCF(pcf_address, &Wire);
PCFStepper stepper(stepsPerRevolution, PCF, 4, 6, 5, 7);

Bounce2::Button button1 = Bounce2::Button();
Bounce2::Button button2 = Bounce2::Button();

RTC_DS1307 rtc;
DateTime last_time, now;
TimeSpan difference;

//int8_t direction = 1;
int8_t switch_input = 0;
int8_t digit_led = HIGH;
int8_t green_led = HIGH;
int8_t yellow_led = LOW;
int8_t hall_sensor = 0;

bool is_homing = false;

void setup() {
  #ifdef SERIAL_DEBUG
    Serial.begin(115200);
    while(!Serial);  //  uncomment when needed
  #endif

  Wire.begin(8, 9);
  
  #ifdef SERIAL_DEBUG
    Serial.println("Initializing PCF...");
  #endif

  if (!PCF.begin())
  {
    #ifdef SERIAL_DEBUG
      Serial.println("could not initialize...");
    #endif
  }
  if (!PCF.isConnected())
  {
    #ifdef SERIAL_DEBUG
      Serial.println("=> not connected");
    #endif
    while(1);
  }

  if (! rtc.begin(&Wire)) {
    #ifdef SERIAL_DEBUG
      Serial.println("Couldn't find RTC");
    #endif
    while (1) delay(10);
  }
  
  #ifdef SERIAL_DEBUG
    Serial.println("Initializing Stepper...");
  #endif

  stepper.begin();
  stepper.setSpeed(10);
  stepper.powerDown();

  #ifdef SERIAL_DEBUG
    Serial.println("Initializing Buttons...");
  #endif

  button1.attach( button1_pin ,  INPUT_PULLUP ); // USE INTERNAL PULL-UP
  button1.interval(10); // DEBOUNCE INTERVAL IN MILLISECONDS
  button1.setPressedState(LOW); // INDICATE THAT THE LOW STATE CORRESPONDS TO PHYSICALLY PRESSING THE BUTTON
  
  button2.attach( button2_pin ,  INPUT_PULLUP ); // USE INTERNAL PULL-UP
  button2.interval(10); // DEBOUNCE INTERVAL IN MILLISECONDS
  button2.setPressedState(LOW); // INDICATE THAT THE LOW STATE CORRESPONDS TO PHYSICALLY PRESSING THE BUTTON

  // Initialize ESP32 pins
  pinMode(switch_pin, INPUT);

  pinMode(led_yellow_pin, OUTPUT);
  pinMode(led_green_pin, OUTPUT);

  digitalWrite(led_yellow_pin, yellow_led);
  digitalWrite(led_green_pin, green_led);

  // Initialize digit pins
  PCF.write(digit_led_red_pin, digit_led);

  if (! rtc.isrunning()) {
    #ifdef SERIAL_DEBUG
      Serial.println("RTC is NOT running, let's set the time!");
    #endif
    // When time needs to be set on a new device, or after a power loss, the
    // following line sets the RTC to the date & time this sketch was compiled
    rtc.adjust(DateTime(F(__DATE__), F(__TIME__)));
    // This line sets the RTC with an explicit date & time, for example to set
    // January 21, 2014 at 3am you would call:
    // rtc.adjust(DateTime(2014, 1, 21, 3, 0, 0));
  }

  last_time = rtc.now();

  #ifdef SERIAL_DEBUG
    int x = PCF.read16();
    Serial.print("Read ");
    Serial.println(x, HEX);
    delay(1000);
  #endif
}

void loop() {
  now = rtc.now();
  difference = now - last_time;

  if (difference.seconds() > 1)
  {
    last_time = now;
    
    #ifdef SERIAL_DEBUG
      char buf2[] = "YYMMDD-hh:mm:ss";
      Serial.println(now.toString(buf2));
    #endif

    green_led = (green_led == HIGH ? LOW : HIGH);
    yellow_led = (yellow_led == HIGH ? LOW : HIGH);

    digitalWrite(led_yellow_pin, yellow_led);
    digitalWrite(led_green_pin, green_led);
  }

  button1.update();
  button2.update();

  switch_input = digitalRead(switch_pin);
  if (switch_input == HIGH) 
  {
    if (button1.pressed())
    {
      #ifdef SERIAL_DEBUG
        Serial.println("Button 1 pressed");
      #endif
      stepper.step(stepsPerNumber);
      stepper.powerDown();
    }
    if (button2.pressed())
    {
      #ifdef SERIAL_DEBUG
        Serial.println("Button 2 pressed");
      #endif
      stepper.step(-stepsPerNumber);
      stepper.powerDown();
    }
  }
  else
  {
    if (button1.pressed())
    {
      #ifdef SERIAL_DEBUG
        Serial.println("Button 1 pressed");
        Serial.println("Homing started");
      #endif
      is_homing = true;
    }
    if (button2.pressed())
    {
      #ifdef SERIAL_DEBUG
        Serial.println("Button 2 pressed");
      #endif
      digit_led = (digit_led == HIGH ? LOW : HIGH);
      PCF.write(digit_led_red_pin, digit_led);
    }
  }

  if (is_homing)
  {
    hall_sensor = PCF.read(digit_hall_sensor_pin);
    #ifdef SERIAL_DEBUG
      Serial.print("Sensor reading: ");
      Serial.println(hall_sensor);
    #endif

    if (hall_sensor == 1) {
      stepper.step(1);
    }
    else {
      is_homing = false;
      stepper.powerDown();
    }
  }
}

// void loop() {
//   now = rtc.now();
//   difference = now - last_time;

//   button1.update();
//   button2.update();

//   switch_input = digitalRead(switch_pin);
//   if (switch_input == HIGH)
//   {
//     direction = 1;
//     digitalWrite(led_yellow_pin, HIGH);
//     digitalWrite(led_green_pin, LOW);
//     stepper.step(1);
//   }
//   else
//   {
//     direction = -1;
//     digitalWrite(led_yellow_pin, LOW);
//     digitalWrite(led_green_pin, HIGH);
//     stepper.powerDown();
//   }

//   if (button1.pressed())
//   {
//     #ifdef SERIAL_DEBUG
//       Serial.println("Button 1 pressed");
//     #endif
//     stepper.step(direction*stepsPerNumber);
//     stepper.powerDown();
//   }

//   if (button2.pressed())
//   {
//     #ifdef SERIAL_DEBUG
//       Serial.println("Button 2 pressed");
//     #endif
//     // stepper.step(-1*direction*stepsPerNumber);
//     // stepper.powerDown();

//     digit_led = (digit_led == HIGH ? LOW : HIGH);
//     PCF.write(digit_led_red_pin, digit_led);
//   }

//   if (difference.seconds() > 10)
//   {
//     last_time = now;
    
//     #ifdef SERIAL_DEBUG
//       char buf2[] = "YYMMDD-hh:mm:ss";
//       Serial.println(now.toString(buf2));
//     #endif

//     digitalWrite(led_yellow_pin, HIGH);
//     digitalWrite(led_green_pin, HIGH);
//     delay(500);
//   }
// }

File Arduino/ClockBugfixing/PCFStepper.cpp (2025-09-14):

#include "Arduino.h"
#include "PCFStepper.h"

/*
 *   constructor for four-pin version
 *   Sets which wires should control the motor.
 */
PCFStepper::PCFStepper(int number_of_steps, PCF8575& pcf8575,
                 int motor_pin_1, int motor_pin_2,
                 int motor_pin_3, int motor_pin_4)
  : pcf8575(pcf8575)
{
  this->step_number = 0;    // which step the motor is on
  this->direction = 0;      // motor direction
  this->last_step_time = 0; // timestamp in us of the last step taken
  this->number_of_steps = number_of_steps; // total number of steps for this motor

  // Arduino pins for the motor control connection:
  this->motor_pin_1 = motor_pin_1;
  this->motor_pin_2 = motor_pin_2;
  this->motor_pin_3 = motor_pin_3;
  this->motor_pin_4 = motor_pin_4;
}

void PCFStepper::begin()
{
  // Initialize stepper pins to LOW (outputs, coils off)
  pcf8575.write(this->motor_pin_1, LOW);
  pcf8575.write(this->motor_pin_2, LOW);
  pcf8575.write(this->motor_pin_3, LOW);
  pcf8575.write(this->motor_pin_4, LOW);
}

/*
 * Sets the speed in revs per minute
 */
void PCFStepper::setSpeed(long whatSpeed)
{
  this->step_delay = 60L * 1000L * 1000L / this->number_of_steps / whatSpeed;
}

/*
 * Moves the motor steps_to_move steps.  If the number is negative,
 * the motor moves in the reverse direction.
 */
void PCFStepper::step(int steps_to_move)
{
  int steps_left = abs(steps_to_move);  // how many steps to take

  // determine direction based on whether steps_to_mode is + or -:
  if (steps_to_move > 0) { this->direction = 1; }
  if (steps_to_move < 0) { this->direction = 0; }


  // decrement the number of steps, moving one step each time:
  while (steps_left > 0)
  {
    unsigned long now = micros();
    // move only if the appropriate delay has passed:
    if (now - this->last_step_time >= this->step_delay)
    {
      // get the timeStamp of when you stepped:
      this->last_step_time = now;
      // increment or decrement the step number,
      // depending on direction:
      if (this->direction == 1)
      {
        this->step_number++;
        if (this->step_number == this->number_of_steps) {
          this->step_number = 0;
        }
      }
      else
      {
        if (this->step_number == 0) {
          this->step_number = this->number_of_steps;
        }
        this->step_number--;
      }
      // decrement the steps left:
      steps_left--;
      // step the motor to step number 0, 1, ..., {3 or 10}
      stepMotor(this->step_number % 4);
    } else {
      yield();
    }
  }
}

void PCFStepper::powerDown()
{
  // Turn off coils to save power
  pcf8575.write(motor_pin_1, LOW);
  pcf8575.write(motor_pin_2, LOW);
  pcf8575.write(motor_pin_3, LOW);
  pcf8575.write(motor_pin_4, LOW);
}

/*
 * Moves the motor forward or backwards.
 */
void PCFStepper::stepMotor(int thisStep)
{
  switch (thisStep) {
    case 0:  // 1010
      pcf8575.write(motor_pin_1, HIGH);
      pcf8575.write(motor_pin_2, LOW);
      pcf8575.write(motor_pin_3, HIGH);
      pcf8575.write(motor_pin_4, LOW);
    break;
    case 1:  // 0110
      pcf8575.write(motor_pin_1, LOW);
      pcf8575.write(motor_pin_2, HIGH);
      pcf8575.write(motor_pin_3, HIGH);
      pcf8575.write(motor_pin_4, LOW);
    break;
    case 2:  //0101
      pcf8575.write(motor_pin_1, LOW);
      pcf8575.write(motor_pin_2, HIGH);
      pcf8575.write(motor_pin_3, LOW);
      pcf8575.write(motor_pin_4, HIGH);
    break;
    case 3:  //1001
      pcf8575.write(motor_pin_1, HIGH);
      pcf8575.write(motor_pin_2, LOW);
      pcf8575.write(motor_pin_3, LOW);
      pcf8575.write(motor_pin_4, HIGH);
    break;
  }
}

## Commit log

2025-09-04 Backup of cad files
    Backup of cad files
2025-09-05 adding cad models
    adding cad models
    [BOM.xlsx, Stepper motor 28BYJ-48 5V.STEP]
2025-09-12 Main Cad models
    [Hall Effect Sensor Sunkee A3144 v4.step, ULN2003 Stepper Driver.stp]
2025-09-14 Adding arduino tests
2025-09-19 Added CAD models
    [BOM.xlsx, ESP32S3 Super Mini.step, LED 3mm Red 3mm Leads.step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]
2025-10-01 Add cad files and arduino sketch
    Added cad files for the DS1307 RTC module
    Added a sketch for the PCA9306 level shifter
    [RTCmodule_DS1307.STEP]
2025-10-28 Working on master module PCB
    [MasterModule.kicad_pcb, MasterModule.kicad_sch, PCB Outline.dxf]
2025-10-28 PCB update
    [MasterModule.kicad_pcb, MasterModule.kicad_sch]
2025-11-23 Added hall sensor and led to digit module
    [7SegmentClock.kicad_pcb, 7SegmentClock.kicad_sch]
2025-12-04 Created (and ordered) the pcb
    [MasterModule.kicad_pcb, MasterModule.kicad_sch, MasterModule.step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]
